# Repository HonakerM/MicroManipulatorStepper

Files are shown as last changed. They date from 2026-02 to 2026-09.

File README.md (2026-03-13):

# Open Micro-Manipulator

This project contains an open source low-cost, easy-to-build motorized **XYZ Micro-Manipulator** motion control platform achieving submicron precision.
It's designed for applications such as optical alignment, probing electronic components, and microscopy.

Check out the YouTube video for more information about the device and how it is built:<br>
[An Open Source Motorized XYZ Micro-Manipulator - Affordable sub µm Motion Control](https://youtu.be/MgQbPdiuUTw)

<div style="display: flex; gap: 2%;">
  
  
</div>

Thanks to its parallel kinematic structure and miniature ball joints, it achieves good mechanical stiffness and a large range of motion.
The motors are off the shelf stepper motors driven by a 30 kHz closed loop controller and a very precise PWM signal.
A 'magnetic gearing' approach increases the resolution of the low-cost magnetic rotary encoders by a factor of 30 allowing for steps down to 50nm
(**Please mind the difference between resolution and accuracy**. The absolute accuracy is significantly worse.

The device can be controlled via simple G-Code commands over a USB serial interface and is thus easily integrated into other projects.
The firmware implements a complete motion planning stack with look-ahead for smooth and accurate path following capabilities.

## Getting Started

Below is a list of high level steps you can follow if you want to replicate the project. 
If you have questions or problems with the build or just want to discuss subjects related to the project, 
joint the projects community [Discord Server](https://discord.gg/maRvMVpa2Q).

1. Read this Document and watch the linked videos
2. Get the parts listed in [Bill of Materials](documentation/bom/bom.md)
3. Build the device and electronics
4. Change the hardware configuration according to your build [hw_config.h](firmware/MotionControllerRP/src/hw_config.h)
5. Upload firmware using VSCode with PlattformIO plugin
6. Calibrate axis

## ✨NEW: Hardware Version 4.0
A new version of the hardware has been released, fixing several issues with the previous design:

- Self collision during homing fixed.
- Connection of ball joint block with screws only was not well constrained and could rotated a bit.
- No reliable way to ensure consistent linkage rod length
- Unnecessary ball joint friction
- Accurate ball position heavily dependet on print quality and corner rounding
- Rubber bands could not be changed or removed once glued in.

A video about the improved ball joint and linkage manufactoring process can be found on YT: [Better Ball Joints for the Open Micro-Manipulator](https://www.youtube.com/watch?v=NM2KXvRGmpg)
Also the FreeCAD model was restructured and improved and now includes all pins and fasteners. It now provides a reference for all required mechanical parts. 

<div style="display: flex;">
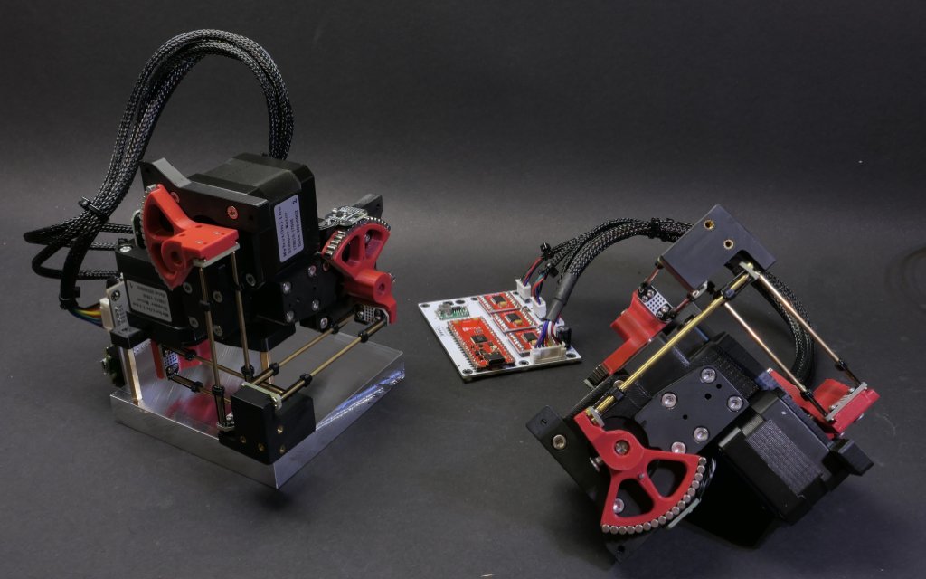
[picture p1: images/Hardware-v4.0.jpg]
Open Micro-Manipulator GUI
    
</div>

WARNING: BOM is not updated yet...

## Open Micro-Manipulator GUI
To make testing and using the Open-Micro Manipulator easy and convenient a python control program with a graphical user interface is provided here: [Open Micro-Manipulator GUI](https://github.com/0x23/OpenMicroManipulatorGUI).
It has simple controlls to move the device around, while also displaying a live camera feed (e.g. from a microscope camera). Additional features, include a simple g-code runner and realtime mouse control (e.g. for Biology applications).

<div style="display: flex;">
    Open Micro-Manipulator GUI
</div>

## 🐍 Python-API

The lightweight Python API handles all serial communication and provides convenient command execution and debug message printing.
The interface includes functions to home, move, and calibrate the device, as well as to query device information.
Simply copy the [open_micro_stage_api.py](software/PythonAPI/open_micro_stage_api.py) file into your project (also install the dependencies in requirements.txt), and you’re ready to get started.

## Usage Example
```python
from open_micro_stage_api import OpenMicroStageInterface

# create interface and connect
oms = OpenMicroStageInterface(show_communication=True, show_log_messages=True)
oms.connect('/dev/ttyACM0')

# run this once to calibrate joints
# for i in range(3): oms.calibrate_joint(i, save_result=True)

# home device
oms.home()

# move to several x,y,z positions [mm]
oms.move_to(0.0, 0.0, 0.0, f=10)
oms.move_to(3.1, 4.1, 5.9, f=26)
oms.move_to(0.0001, 0.0, 0.0, f=10)

# wait for moves to finish
oms.wait_for_stop()
```

## API Functions (most relevant functions only)
```python
connect(port, baud_rate=921600)
disconnect()
set_workspace_transform(transform)
get_workspace_transform()
home(axis_list=None)
calibrate_joint(joint_index, save_result)
move_to(x, y, z, f, move_immediately, blocking, timeout)
set_tool_output(tool_idx, output_value, immediate)
set_pose(x, y, z)
dwell(time_s, blocking, timeout)
enable_motors(enable)
wait_for_stop(polling_interval_ms, disable_callbacks)
set_max_acceleration(linear_accel, angular_accel)
set_servo_parameter(pos_kp, pos_ki, vel_kp, vel_ki, vel_filter_tc)
```
## ✨ Firmware v1.0.4

Firmware 1.0.4 comes with many smaller improvements and bugfixes and a great new feature as well:

 - **Tools**: Tool usage (for example for laser engraving) is now supported on the two GPIO pins of J5 on the pcb.
              Tools are integrated into the planner and run fast and with correct timing when executing g-code.
              The tools support PWM (using the PIO feature to squeeze out extra channels without relying on software PWM).

   Example usage:
   ```
     M3 T0 S0.7  // set pwm output of tool 0 to 70%
     G4 S0.001   // dwell command (or any other motion command) - necessary to apply the tools output
   ```
   
- **Calibration**: Calibration has now some addition error checks to improve error reporting of potential problems like encoder alignment.
- **Kinematic Model Parameter**: Initialization code has been cleaned up and better comments where added to the parameters. Parameters are preset for HW v4.0 but you can toggle back to the old HW-v3.0 parameters if necessary.
- **Bugfixes**: smaller bugfixes

IMPORTANT: If you have **Hardware Version v3.0** you need to switch back to the old kinematic parameters in the [kinematic_model_delta3d.cpp](firmware/MotionControllerRP/src/kinematic_models/kinematic_model_delta3d.cpp) file (there is an #define for that at the top).

## Firmware v1.0.1

This update improves calibration, homing, logging, and adds several new G-Code commands.

### Improvements
- **Homing**: parallel homing support, higher repeatability, more accurate geometric reference  
- **Joint calibration**: refined procedure, persistent flash storage (no recalibration after reboot)  
- **Logging**: clearer and more detailed output  

### New G-Code Commands
- `G28` — Home joints (supports homing multiple axis simultanously for faster startup)
- `G24` — Set pose command (directly sets servo targets, bypassing motion controller)  
- `M17/M18` — Enable/Disable motors (with pose recovery from encoders on enable)  
- `M51` — Read encoder values  
- `M55` — Set servo loop parameters 
- `M56` — Joint calibration (with save-to-flash option)  
- `M57` — Read various information about the device state  
- `M58` — Read firmware version

## ⚙ CAD-Files

All CAD models are made in **FreeCAD** to allow everyone to view and modify the design without subscribing or paying for a proprietary CAD solution.
Note that most components are already designed with the goal to make them easily machinable on a 3-Axis CNC-Mill.
You can also 3D-Print the parts but have to live with thermal drift (carbon filled filaments can reduce this problem).

<div style="display: flex;">
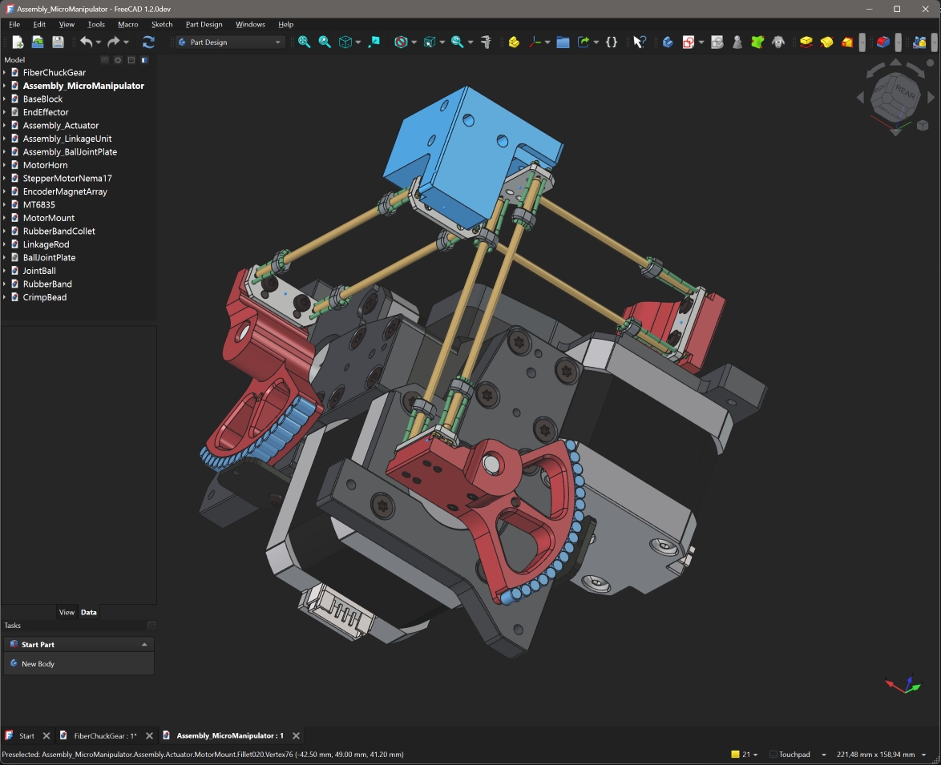
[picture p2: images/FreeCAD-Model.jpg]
FreeCAD Model
    
</div>

<br>

The CAD files can be found here: [CAD Models](construction).
Please note that FreeCAD version **1.2.0dev** was used, and the files might not work with older versions.

STL files for printing can be found here: [STL Files](construction/STL_3D_Printing/)

## ⚙ Kinematic Model

The kinematic model is defined here: [kinematic_model_delta3d.cpp](firmware/MotionControllerRP/src/kinemtaic_models/kinematic_model_delta3d.cpp).
Please check the dimensions of your build against the values set in the constructor. In particular, make sure the arm length matches.

## ⚙ Electronics

IMPORTANT: If you fabricated PCB version v1.2 (see version label on the board) you need to drill out a misplaced via on diode D1 that shorts 5V rail to ground (See [repair image](electronics/pcb_v1.2_fix.jpg) ). The problem was fixed in v1.3.

The electronics are designed in **KiCAD** and only commonly available modules (motor drivers and MCU boards) are used and connected by a simple PCB. No SMD soldering is required to populate the board to make the build extra accessible.
For usual winding resistance of your motors, the device should be powered by $${\color{lightgreen} 5V-6V }$$ (2A) to keep current and heating to a reasonable level.

<div style="display: flex; gap: 5%;">
  
  
</div>

The repository now also contains the fabrication files that can be directly uploaded to the PCB manufacturer.

## ⚙ Firmware

The firmware is written in C++ and takes some inspiration from the 'SimpleFOC' project. It aims to be streamlined and readable without any extra fuss, focusing on the hardware used in this project.
It implements path planning with look-ahead and, unlike many other motion controller projects, supports true 6DOF-Pose interpolation and planning, making it ready for driving hexapod motion platforms; that may or may not be the next step for this project.

You may find configuration for pin numbers, motor type, and other parameters in [hw_config.h](firmware/MotionControllerRP/src/hw_config.h). Please check them before uploading the firmware.

<div style="display: flex; gap: 2%;">
  
  
</div>

### Building and Flashing the Firmware

For building and flashing the firmware, Visual Studio Code (available for free on Windows and Linux) is recommended.
Install the PlatformIO add-on and open the firmware folder. You can now build and flash the firmware like any other PlatformIO project.

## ⚙ G-Code Interface

The firmware supports only a small subset of G-Code commands listed below.  
Each command is acknowledged with either an **`ok`** or **`error`** response.  

If a command provides additional information (e.g., the *get position* command), that information is returned **before** the `ok` message.  
The client must wait for an acknowledgment from the previous command before sending the next one—otherwise, behavior is undefined.
| Command | Description |
|---|---|
| `G0 X Y Z F` | Move the end-effector in a straight line to the specified position. <br>• `X`, `Y`, `Z`: target positions <br>• `F`: feed rate |
| `G1 X Y Z F` | Same as `G0`. |
| `G4 S/P` | Dwell/pause for a specified time. <br>• `S`: seconds <br>• `P`: milliseconds |
| `G24 X Y Z A B C` | Directly set current pose for servo loops with optional rotation vector* `A`, `B`, `C`. |
| `G28 A-F` | Home one or more joints. <br>• Optional joint selection `A`–`F`. |
| `M3` | Set Tool output. <br>• `T`: tool index <br>• `S`: output value (0.0..1.0) <br> Note: new values is only applied on the next motion or dwell command |
| `M17` | Enable motors and read current pose as the start pose. |
| `M18` | Disable motors. |
| `M50` | Get current internal pose. (Encoders are not read here) |
| `M51` | Get current encoder angles (in degrees) and raw encoder values. |
| `M52` | Get the number of items in the planner queue. |
| `M53` | Check if all planned moves are finished (`1` = finished, `0` = not finished). |
| `M55 A B C D F` | Set servo loop parameters. <br>• `A`, `B`: position PI controller gains (P and I) <br>• `C`, `D`: velocity PI controller gains (P and I) <br>• `F`: velocity filter time constant |
| `M56 J S` | Calibrate a joint. <br>• `J`: joint index <br>• `S`: save calibration result |
| `M57` | Get device and servo loop info: homing/calibration state, angles, loop frequencies, and file list. |
| `M58` | Get firmware version. |
| `M204 L A` | Set linear and angular acceleration. <br>• `L`: linear acceleration <br>• `A`: angular acceleration |

*Note: The communication protocol uses 3D vectors for rotations. The direction represents the rotation axis and the length of the vector represents the angle of rotation around the axis.

## ❤️ Support

If you'd like to support this project, consider the following:

- **Contribute to the build guide** – Help improve or expand the build instructions by submitting pull requests or opening issues with suggestions.
- **Characterize typical radial stepper motor shaft error motion** – Measure radial error motion of the shaft of multiple Nema-17 stepper motors (see Cylos Garage for more information about the subject: https://www.youtube.com/watch?v=gt2gK-oxy5s).
- **Give feedback on the build experience** – Let us know what worked, what didn’t, and how the process could be smoother for others.
- **Support the project on Ko-fi** – If you find this project valuable, you can support it financially via [Ko-fi](https://ko-fi.com/diffractionlimited) ☕.

## Youtube Video
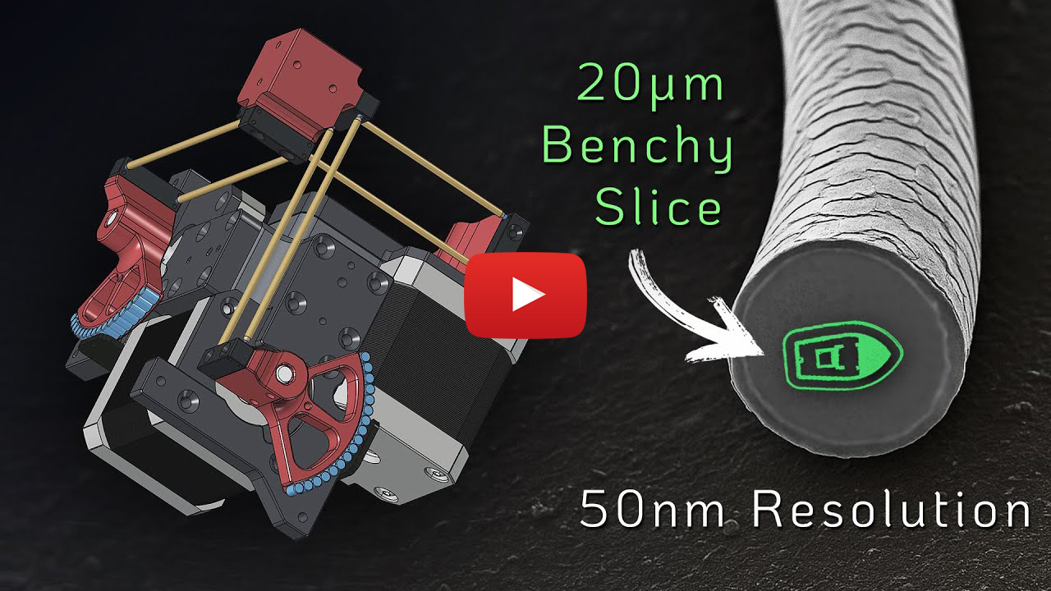
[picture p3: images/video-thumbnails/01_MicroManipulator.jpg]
Watch the video (https://youtu.be/MgQbPdiuUTw)

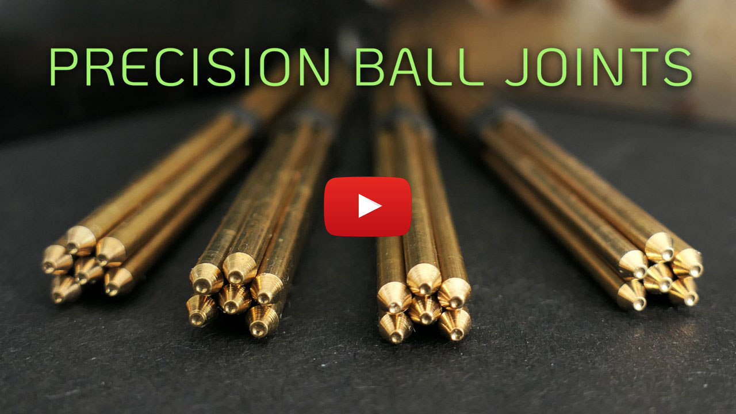
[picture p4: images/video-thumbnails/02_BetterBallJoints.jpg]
Better Ball Joints for the Open Micro-Manipulator (https://youtu.be/MgQbPdiuUTw)


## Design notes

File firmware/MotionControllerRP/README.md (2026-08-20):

# MotionControllerRP -- pico-sdk + FreeRTOS port

This is a port of the original PlatformIO / arduino-pico project to plain CMake +
pico-sdk + FreeRTOS, targeting the Raspberry Pi Pico 2 (RP2350). See
[`lib/README.md`](lib/README.md) for the three git submodules you need before building,
and build instructions.

## What changed, and why

**The two bare-metal busy loops are now FreeRTOS tasks.** `main_core0()`
(command-parser + path-planner) and `main_core1()` (servo control) used to be
un-yielding `while(true)` loops, one launched via arduino-pico's `setup()`/`loop()` on
core 0, the other via `multicore_launch_core1()` on core 1. They're now two FreeRTOS
tasks (`command_task` / `servo_task` in `src/main.cpp`), each pinned to its own core
with `vTaskCoreAffinitySet()`, running under the dual-core SMP FreeRTOS port
(`RP2350_ARM_NTZ`, from the `raspberrypi/FreeRTOS-Kernel` fork). This gives you actual
task/scheduler visibility (stack high-water marks, the ability to add more tasks
later, mutexes/queues that interoperate with `pico_sync`, etc.) instead of the cores
being permanently and opaquely owned by one loop each.

**Both tasks still run essentially flat-out**, matching the original behaviour: each
loop iteration ends with `taskYIELD()` rather than a real `vTaskDelay()`, so no
artificial rate limit is imposed on either the command-parsing/path-planning loop or
the servo control loop's update rate (the servo loop still computes its own `dt` from
`time_us_64()` every iteration, exactly as before). `taskYIELD()` just gives the
scheduler on that core a chance to run the idle task / timer service / anything else
you add later, without slowing this one down.

If you'd rather have the servo loop run at a fixed, deterministic rate instead (e.g.
to guarantee CPU headroom on core 1 for future tasks, at the cost of some peak
throughput), there's a comment in `servo_task()` in `main.cpp` showing how to swap the
`taskYIELD()` for a `vTaskDelayUntil()` against a fixed period.

**Arduino-framework dependencies were replaced with a small compatibility layer**
(`src/compat/`), rather than rewriting the control/kinematics/servo code itself:

| Arduino API | Replaced by | Backed by |
|---|---|---|
| `Serial` | `compat/Serial_compat.*` | pico-sdk stdio over USB CDC |
| `Wire` / `TwoWire` | `compat/Wire_compat.*` | pico-sdk `hardware_i2c` |
| `LittleFS` / `File` | `compat/LittleFS_compat.*` | [pico-vfs](https://github.com/oyama/pico-vfs) (POSIX `fopen`/`opendir`/`stat` on littlefs-over-flash) |
| `delay()` / `delayMicroseconds()` | `compat/Arduino_compat.h` | `sleep_ms()` / `sleep_us()` |

This was a deliberate choice: everything else in this codebase (SPI encoders, the
PWM/PIO motor driver, hardware timers, the multicore spinlocks) was already written
directly against pico-sdk, not Arduino, so the actual Arduino surface area in use was
small and self-contained. Shimming it kept the diff to the control/robotics logic
essentially zero, versus a much riskier full rewrite of files that are hard to
re-verify by eye (PID loops, kinematics, calibration).

One piece of dead code was dropped rather than ported: a `NeoPixelConnect` status-LED
object was instantiated in `robot.cpp` but never actually used anywhere. If you want
status-LED support back, drive the WS2812 directly with the PIO program from
`pico-examples/pio/ws2812` and wire it into `set_led_color()` in `main.cpp`.

**Calibration data (`LittleFS`) and single-core flash writes.** pico-vfs's flash
block device already wraps its erase/program operations in pico-sdk's
`flash_safe_execute()`, which is the mechanism that keeps flash writes safe with
respect to code executing (from flash) on the other core. Per your note, all flash
writes in this project happen from a single core, which is the simpler and
lower-risk case; you shouldn't need `PICO_COPY_TO_RAM` for that. If you ever do move
calibration saves to run from both cores, re-check pico-vfs's
[`LIMITATION.md`](https://github.com/oyama/pico-vfs/blob/main/LIMITATION.md#file-system-limitations)
first.

**Overclocking, hardware timers, multicore spinlocks, SPI encoders, and the PIO-based
motor driver are all unchanged** -- they were already plain pico-sdk and didn't need
touching.

## Verified

This exact tree (with the three submodules from `lib/README.md` checked out) was
built end-to-end against a real `arm-none-eabi-gcc` + `cmake`/`ninja` toolchain while
this port was put together, and compiled and linked cleanly into a `.uf2`. A handful
of real issues surfaced only by actually compiling it were fixed along the way:
missing `hardware_pio`/`hardware_dma` link libraries, a couple of Arduino-only macros
(`PI`, `DEG_TO_RAD`) with no pico-sdk equivalent, and a couple of missing standard
includes (`hardware/sync.h`, `<cstdio>`) that arduino-pico used to pull in for free
via `Arduino.h`.

## Suggested next steps

- Build it yourself against your actual hardware and confirm the servo loop's
  achieved update rate matches what you had before (it should, given the
  `taskYIELD()`-not-`vTaskDelay()` choice above, but worth confirming on-device).
- If you add more tasks later (telemetry, a watchdog, etc.), give them explicit
  priorities/affinities in `main.cpp` alongside `command_task`/`servo_task`.
- `configTOTAL_HEAP_SIZE` in `FreeRTOSConfig.h` is set to 128KB and
  `PICO_FS_DEFAULT_SIZE`/the `pico_enable_filesystem(... SIZE ...)` call in
  `src/CMakeLists.txt` reserves 512KB of flash for the littlefs volume -- both are
  reasonable starting points, tune to taste.

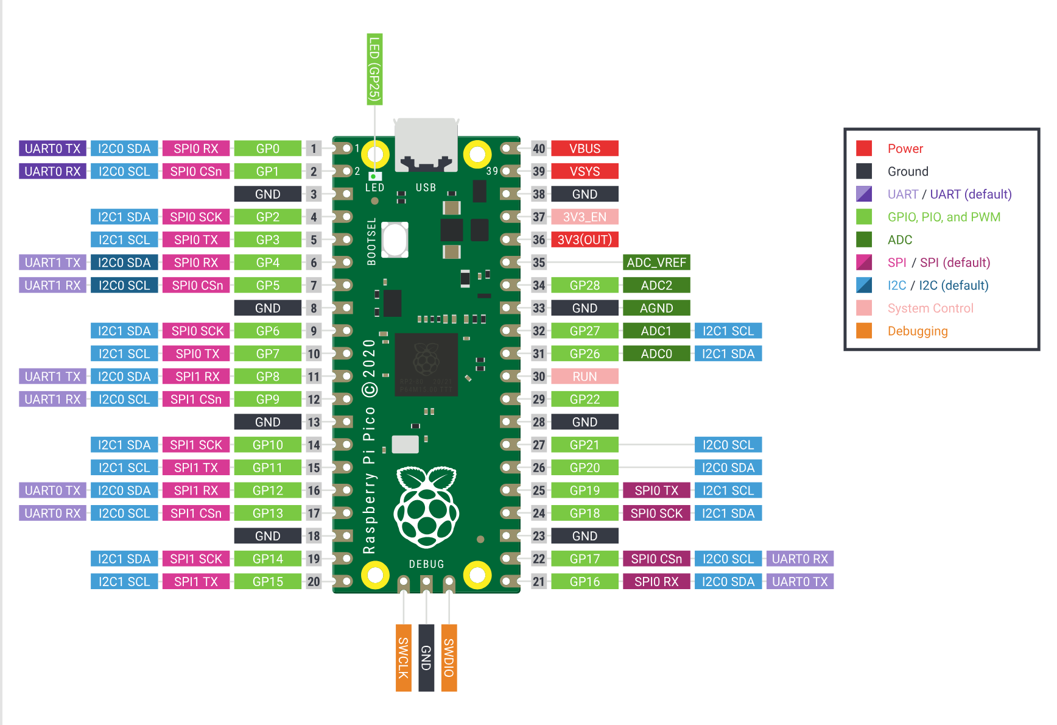
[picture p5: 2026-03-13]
firmware/MotionControllerRP/Rp2350-Pico_Pinout.png

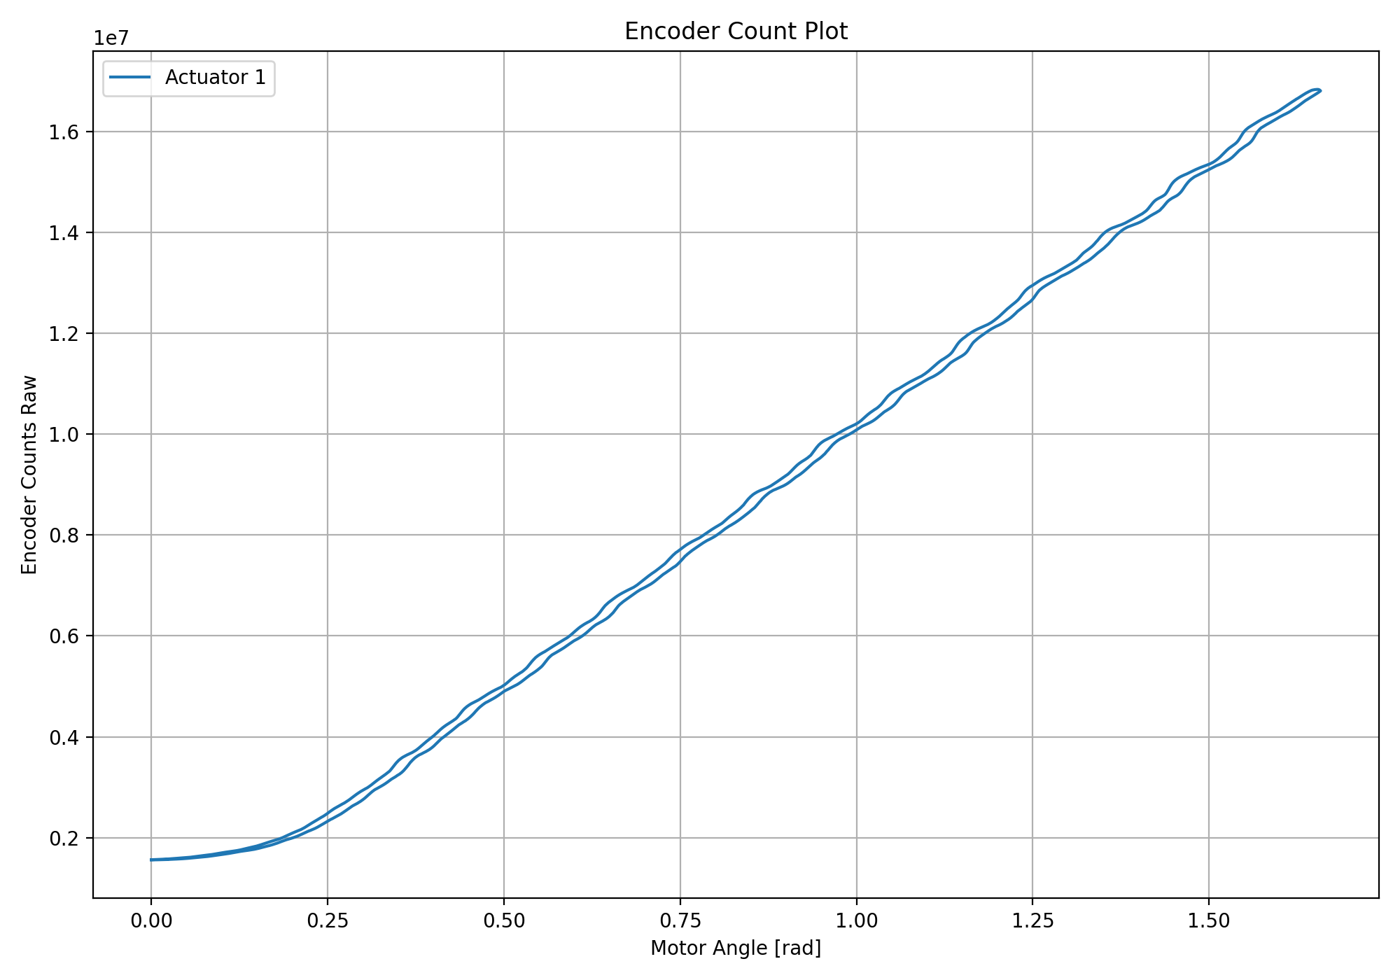
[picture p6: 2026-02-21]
software/PythonAPI/my_figure.png

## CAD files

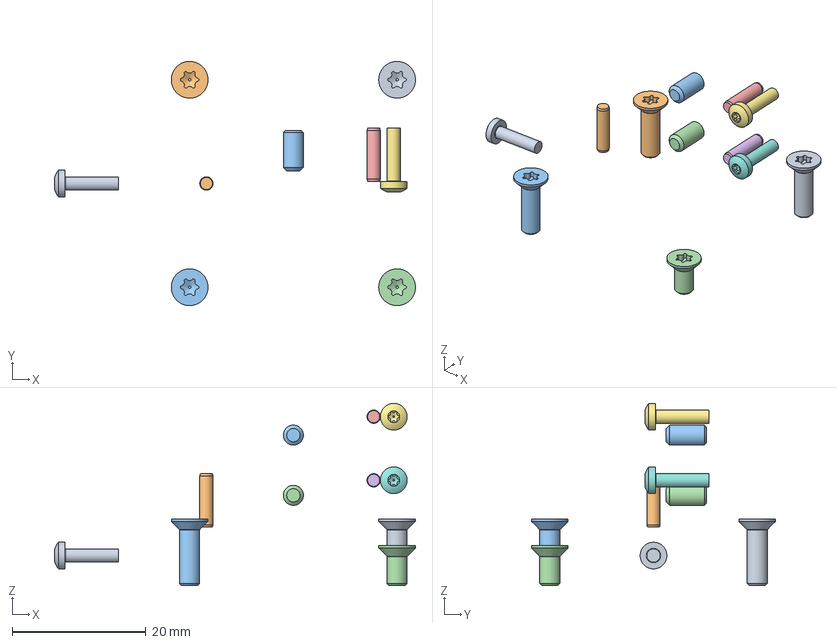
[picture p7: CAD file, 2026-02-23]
construction/micro_manipulator/Assembly_Actuator.FCStd
53.9 x 36.5 x 27.2 mm
M3x10-Screw x 2
M3x10-Screw008 x 2
M3x10-Screw009 x 2
M3x6-Screw x 2
2 mmx8-Pin x 2
2 mmx8-Pin012 x 2
M2x8-Screw x 2
M2x8-Screw009 x 2
M2x8-Screw004 x 2
2 mmx8-Pin011 x 2
M3x6-Screw003 x 2
M3x6-Screw004 x 2

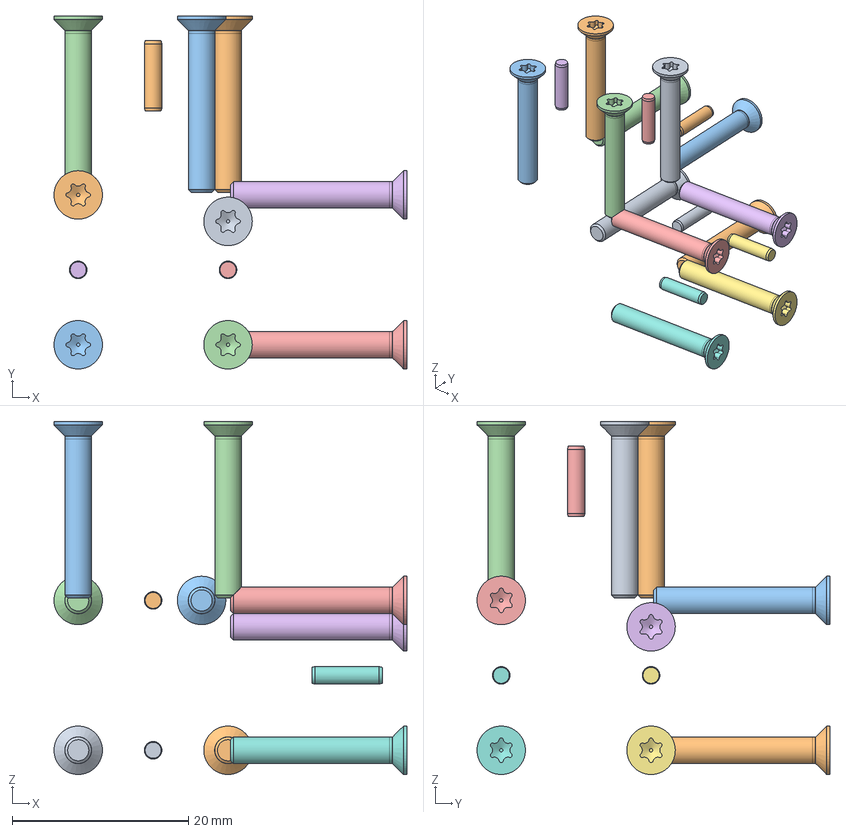
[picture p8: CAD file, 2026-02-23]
construction/micro_manipulator/Assembly_MicroManipulator.FCStd
40.0 x 40.0 x 40.0 mm
M3x20-Screw x 2
M3x20-Screw281 x 2
M3x20-Screw282 x 2
M3x20-Screw283 x 2
M3x20-Screw277 x 2
M3x20-Screw278 x 2
M3x20-Screw279 x 2
M3x20-Screw280 x 2
M3x20-Screw262 x 2
M3x20-Screw263 x 2
M3x20-Screw264 x 2
M3x20-Screw265 x 2
2 mmx8-Pin027 x 2
2 mmx8-Pin028 x 2
2 mmx8-Pin029 x 2
2 mmx8-Pin030 x 2
2 mmx8-Pin031 x 2
2 mmx8-Pin032 x 2

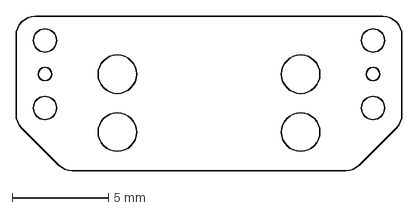
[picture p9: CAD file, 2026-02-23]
construction/micro_manipulator/balljoint_plate_pcb/BallJointPlate-Contour.dxf
20.0 x 8.00 mm

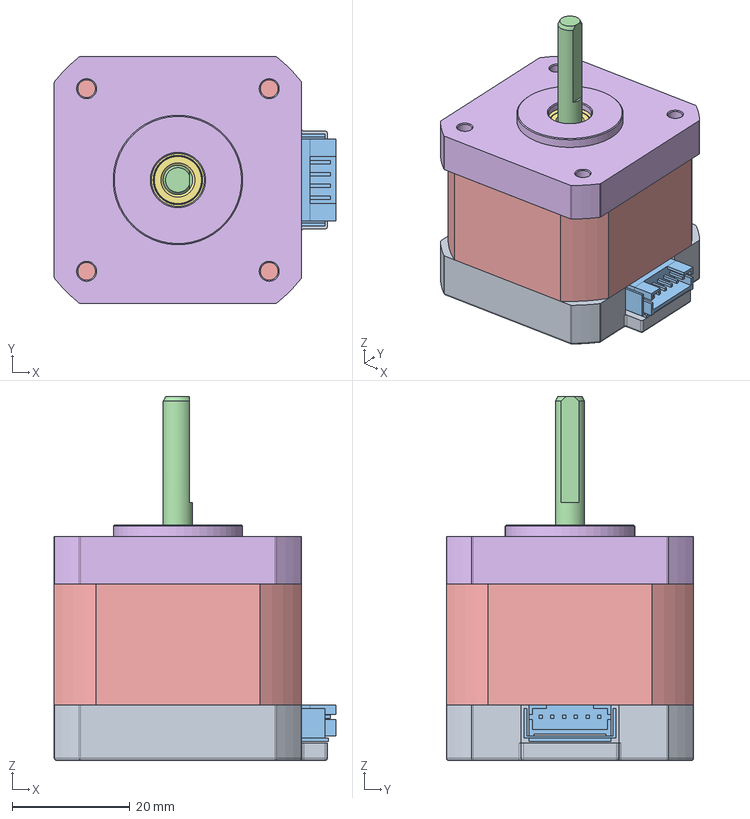
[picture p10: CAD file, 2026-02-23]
construction/micro_manipulator/StepperMotorNema17.FCStd
47.8 x 42.0 x 61.8 mm
rear end cap
rear bearing
connector
shaft
stator
front end cap
front bearing
M3x10-Screw
M3x10-Screw004
M3x10-Screw005
M3x10-Screw006

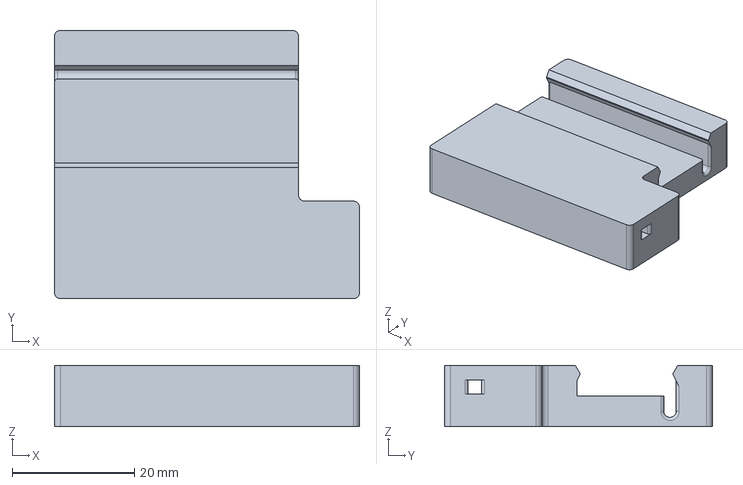
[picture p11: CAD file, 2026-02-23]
construction/tools/rod_embossing_tools/rod_lenth_setting_press/rod_guide.FCStd
50.0 x 44.0 x 10.0 mm

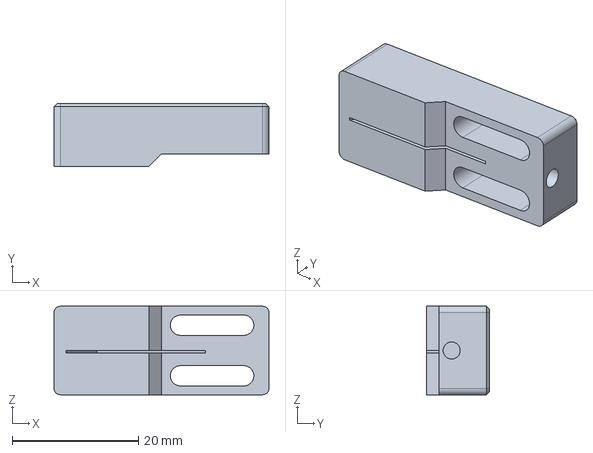
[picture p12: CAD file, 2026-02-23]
construction/tools/rod_embossing_tools/rod_sharper/BladeCarrier.FCStd
34.0 x 10.0 x 14.0 mm

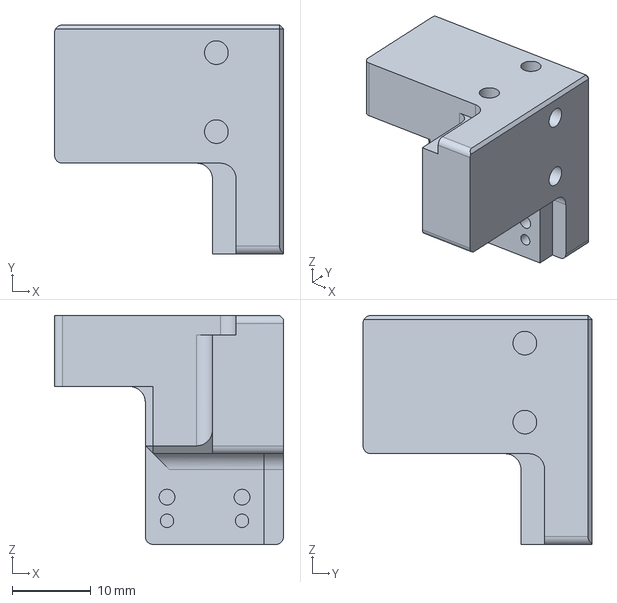
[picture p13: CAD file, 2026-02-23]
construction/micro_manipulator/EndEffector.FCStd
29.0 x 29.0 x 29.0 mm

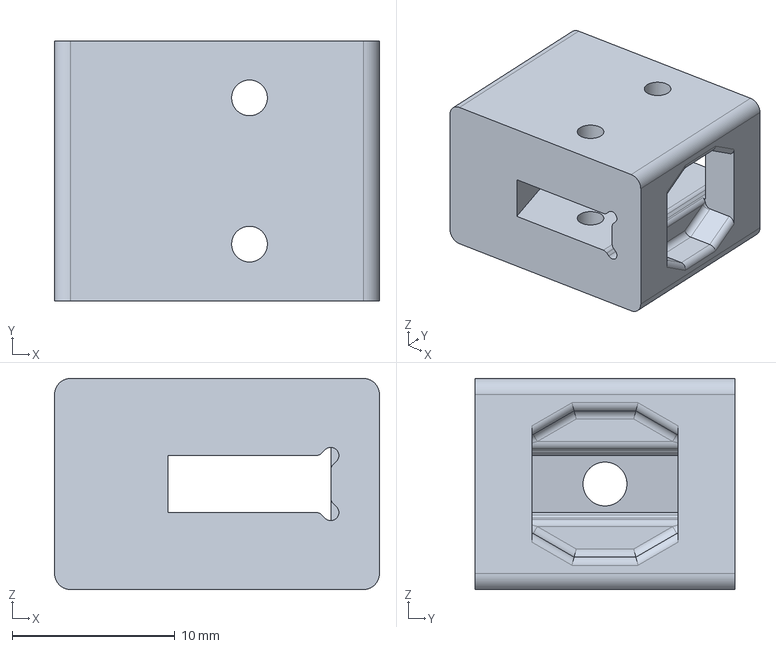
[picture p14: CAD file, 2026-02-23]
construction/tools/rod_embossing_tools/rod_lenth_setting_press/caliper_clamp.FCStd
20.0 x 16.0 x 13.0 mm

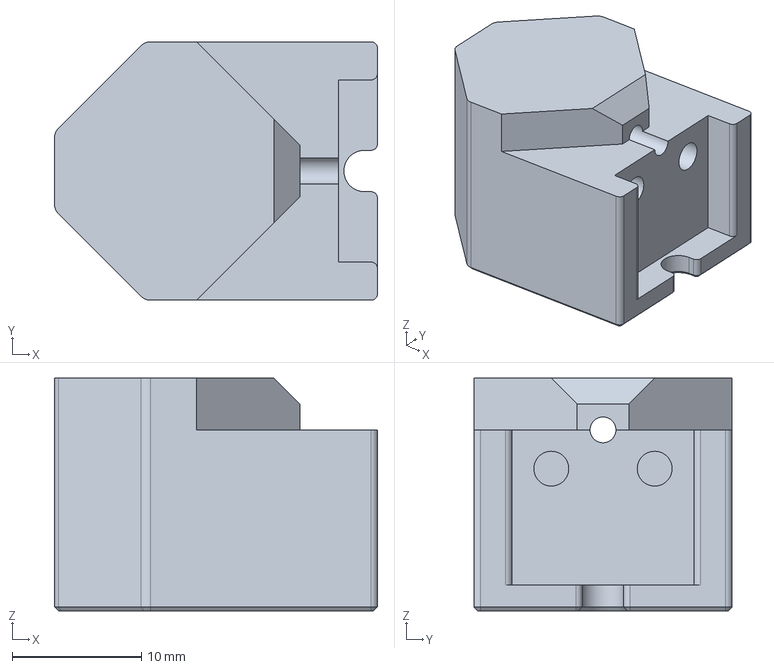
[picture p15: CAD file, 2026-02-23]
construction/tools/rod_embossing_tools/rod_sharper/RodGuide.FCStd
25.0 x 20.0 x 18.0 mm

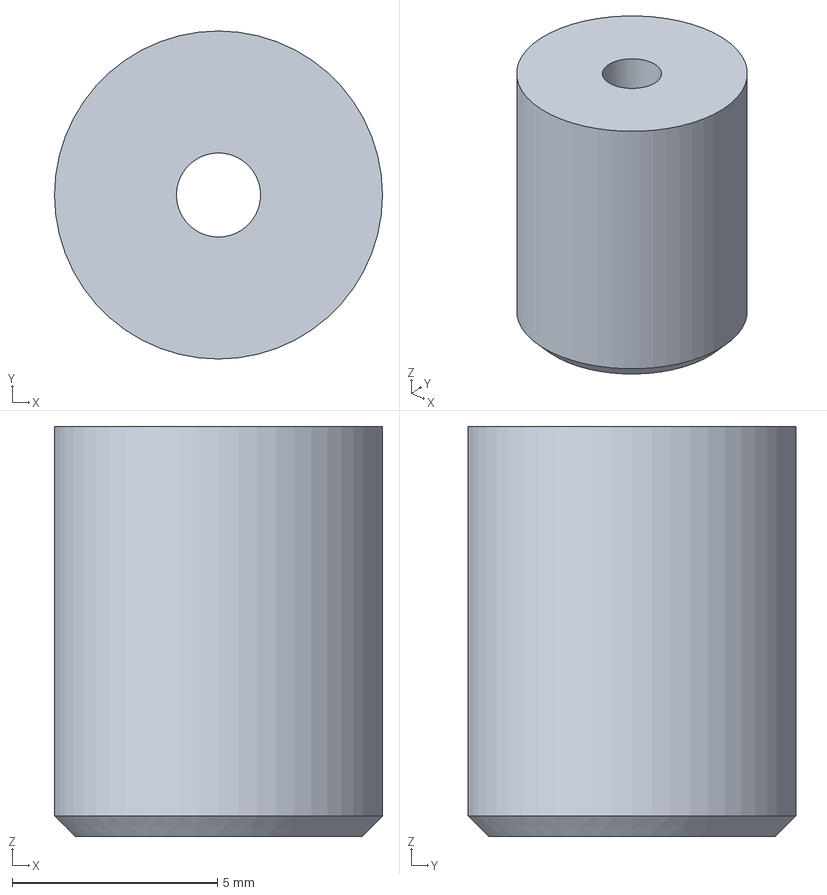
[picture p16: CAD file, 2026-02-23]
construction/tools/rod_embossing_tools/rod_lenth_setting_press/rod_collet.FCStd
8.00 x 8.00 x 10.0 mm

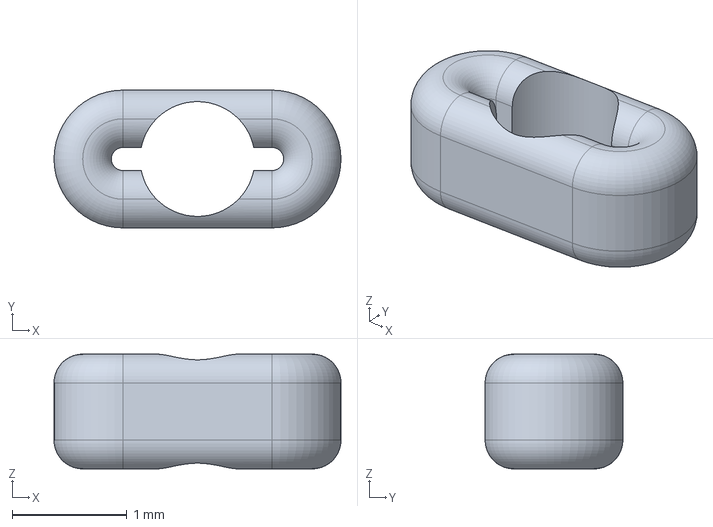
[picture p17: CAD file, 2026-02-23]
construction/micro_manipulator/CrimpBead.FCStd
2.50 x 1.20 x 1.00 mm

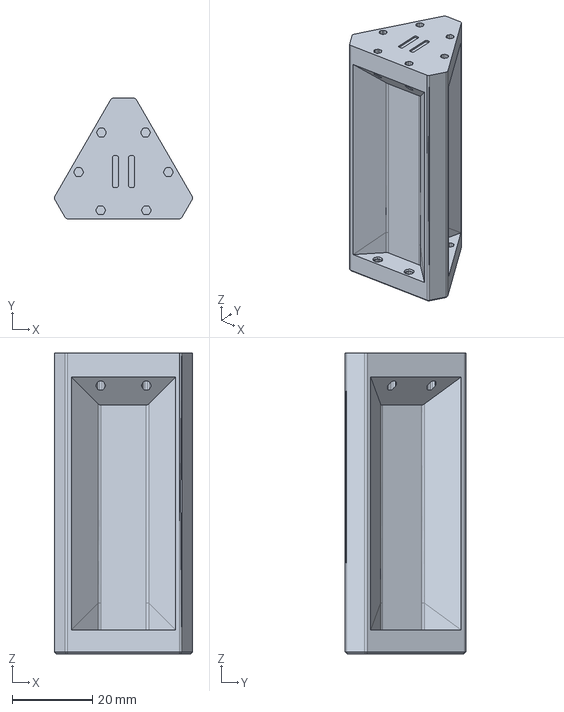
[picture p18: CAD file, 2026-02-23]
construction/tools/rod_embossing_tools/rod_lenth_setting_press/RodGrindingJig_B.FCStd
34.5 x 30.1 x 75.0 mm

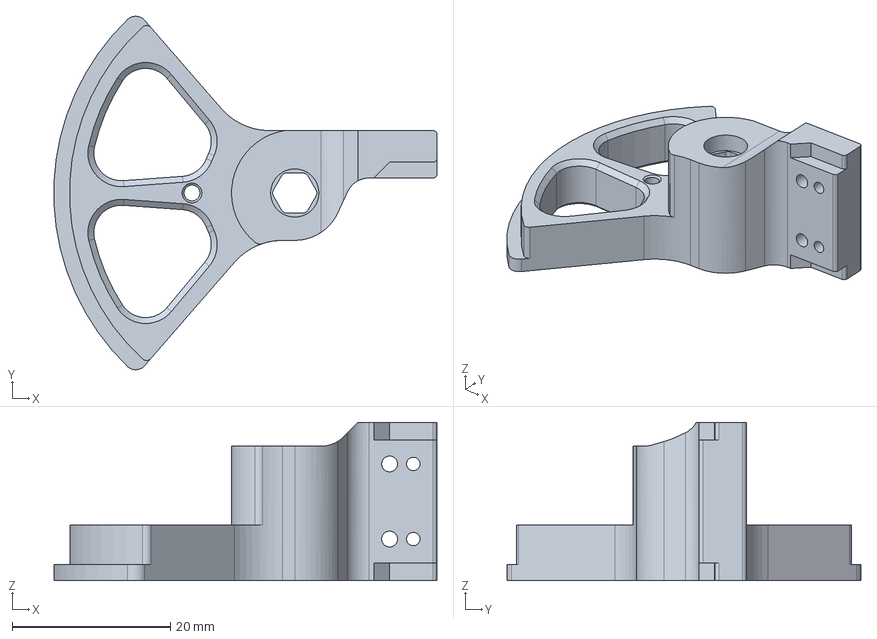
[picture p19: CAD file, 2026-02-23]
construction/micro_manipulator/MotorHorn.FCStd
48.5 x 44.7 x 20.0 mm

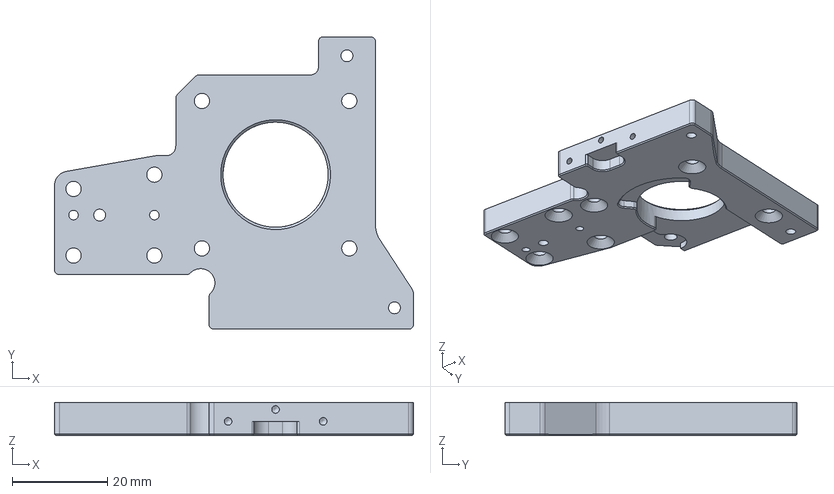
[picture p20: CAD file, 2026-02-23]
construction/micro_manipulator/MotorMount.FCStd
75.5 x 61.5 x 7.00 mm

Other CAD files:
construction/micro_manipulator/Assembly_EndEffector.FCStd
construction/micro_manipulator/Assembly_BallJointPlate.FCStd
construction/micro_manipulator/Assembly_LinkageUnit.FCStd
construction/tools/rod_embossing_tools/rod_lenth_setting_press/RodGrindingJig_A.FCStd
construction/micro_manipulator/BallJointPlate.FCStd
construction/micro_manipulator/BaseBlock.FCStd
construction/micro_manipulator/EncoderMagnet.FCStd
construction/micro_manipulator/EncoderMagnetArray.FCStd
construction/micro_manipulator/JointBall.FCStd
construction/micro_manipulator/LinkageRod.FCStd
construction/micro_manipulator/MT6835.FCStd
construction/micro_manipulator/RubberBand.FCStd
construction/micro_manipulator/RubberBandCollet.FCStd

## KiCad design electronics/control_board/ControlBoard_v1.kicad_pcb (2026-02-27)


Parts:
A1: RaspberryPi_Pico; RaspberryPi_Pico_Common_Unspecified
C1, C2, C3: C_Polarized; CP_Radial_D8.0mm_P3.50mm
C4, C5, C6: C; C_0603_1608Metric_Pad1.08x0.95mm_HandSolder
D1: 1N5819; D_DO-41_SOD81_P10.16mm_Horizontal
D2: PMEG4010; D_SOD-123F
H1, H2, H3, H4, H5, H6: MountingHole_Pad; MountingHole_2.7mm_M2.5_Pad_Via
J1: Motor1; PinHeader_1x04_P2.54mm_Vertical
J2: Motor2; PinHeader_1x04_P2.54mm_Vertical
J3: Motor3; PinHeader_1x04_P2.54mm_Vertical
J4: Encoder; JST_PH_B8B-PH-K_1x08_P2.00mm_Vertical
J5: I2C; JST_PH_B4B-PH-K_1x04_P2.00mm_Vertical
J7: Power; AMASS_XT60-M_1x02_P7.20mm_Vertical
R1, R2: 4K7; R_0603_1608Metric_Pad0.98x0.95mm_HandSolder
U1, U2, U3: ROB-14450; MODULE_ROB-14450; PARTREV 11-13-17
U4: DCDC_Converter; DCDC_17mmx12mm

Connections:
+3.3V: A1.36 (3V3), C4.1, C5.1, C6.1, J4.2, J5.4, R1.1, R2.1, U1.2 (VCC), U2.2 (VCC), U3.2 (VCC)
+5V: A1.39 (VSYS), D1.1 (K), D2.1 (K)
+12V: C1.1, C2.1, C3.1, J7.2, U1.1 (VM), U2.1 (VM), U3.1 (VM), U4.2 (IN+)
/Encoder1_CS: A1.26 (GPIO20), J4.6
/Encoder2_CS: A1.27 (GPIO21), J4.7
/Encoder3_CS: A1.29 (GPIO22), J4.8
/Encoder_MISO: A1.1 (GPIO0), J4.4
/Encoder_MOSI: A1.5 (GPIO3), J4.3
/Encoder_SCK: A1.4 (GPIO2), J4.5
/I2C_SCL: A1.21 (GPIO16), J5.3, R1.2
/I2C_SDA: A1.22 (GPIO17), J5.2, R2.2
/Motor1_A1: A1.17 (GPIO13), U1.14 (AI1)
/Motor1_A2: A1.16 (GPIO12), U1.15 (AI2)
/Motor1_B1: A1.19 (GPIO14), U1.12 (BI1)
/Motor1_B2: A1.20 (GPIO15), U1.11 (BI2)
/Motor2_A1: A1.12 (GPIO9), U2.14 (AI1)
/Motor2_A2: A1.11 (GPIO8), U2.15 (AI2)
/Motor2_B1: A1.14 (GPIO10), U2.12 (BI1)
/Motor2_B2: A1.15 (GPIO11), U2.11 (BI2)
/Motor3_A1: A1.7 (GPIO5), U3.14 (AI1)
/Motor3_A2: A1.6 (GPIO4), U3.15 (AI2)
/Motor3_B1: A1.9 (GPIO6), U3.12 (BI1)
/Motor3_B2: A1.10 (GPIO7), U3.11 (BI2)
/MotorEN: A1.24 (GPIO18), U1.13 (STBY), U2.13 (STBY), U3.13 (STBY)
/MotorPWM: A1.25 (GPIO19), U1.10 (PWMB), U1.16 (PWMA), U2.10 (PWMB), U2.16 (PWMA), U3.10 (PWMB), U3.16 (PWMA)
GND: A1.3 (GND), A1.8 (GND), A1.13 (GND), A1.18 (GND), A1.23 (GND), A1.28 (GND), A1.33 (AGND), A1.38 (GND), C1.2, C2.2, C3.2, C4.2, C5.2, C6.2, J4.1, J5.1, J7.1, U1.3 (GND), U1.8 (GND), U1.9 (GND), U2.3 (GND), U2.8 (GND), U2.9 (GND), U3.3 (GND), U3.8 (GND), U3.9 (GND), U4.1 (IN-), U4.3 (OUT-)
unnamed: D1.2 (A), D2.2 (A), U4.4 (OUT+)
unnamed: J1.1, U1.7 (B01)
unnamed: J1.2, U1.6 (B02)
unnamed: J1.3, U1.5 (A02)
unnamed: J1.4, U1.4 (A01)
unnamed: J2.1, U2.7 (B01)
unnamed: J2.2, U2.6 (B02)
unnamed: J2.3, U2.5 (A02)
unnamed: J2.4, U2.4 (A01)
unnamed: J3.1, U3.7 (B01)
unnamed: J3.2, U3.6 (B02)
unnamed: J3.3, U3.5 (A02)
unnamed: J3.4, U3.4 (A01)

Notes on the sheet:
PWM pin is usually not used in this application and is always 1
Motor Driver 2
Power
Interfaces
Motor Driver 1
Motor Driver 3
Mechanical
Populate one of these diodes.
Micro Controller



Board: 2 copper layers, 64.0 x 85.0 mm, 27 parts (6 on the bottom side), 39 nets.

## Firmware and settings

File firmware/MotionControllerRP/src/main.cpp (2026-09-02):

// --------------------------------------------------------------------------------------
// Project: MicroManipulatorStepper
// License: MIT (see LICENSE file for full description)
//          All text in here must be included in any redistribution.
// Author:  M. S. (diffraction limited)
// --------------------------------------------------------------------------------------

#include "main.h"

#include "hardware/clocks.h"
#include "hardware/pll.h"
#include "hardware/vreg.h"

#include <Wire.h>
#include <algorithm>

#include "robot.h"
#include "utilities/logging.h"
#include "utilities/frequency_counter.h"
#include "kinematic_models/kinematic_model_delta3d.h"
#include "version.h"
#include "hw_config.h"
#include "LittleFS.h"

#include "demo_gcode_generator.h"

//*** GLOBALS ***************************************************************************

// NeoPixelConnect strip(PIN_BUILTIN_LED, 1);
Robot robot(0.01f);

/*
MT6835Encoder encoder1(spi0, PIN_ENCODER1_CS);
MT6835Encoder encoder2(spi0, PIN_ENCODER2_CS);
MT6835Encoder encoder3(spi0, PIN_ENCODER3_CS);

TB6612MotorDriver motor_driver1(
  PIN_MOTOR_EN, PIN_M1_PWM_A_POS, PIN_M1_PWM_A_NEG, PIN_MOTOR_PWMAB,
  PIN_MOTOR_EN, PIN_M1_PWM_B_POS, PIN_M1_PWM_B_NEG, PIN_MOTOR_PWMAB
);
TB6612MotorDriver motor_driver2(
  PIN_MOTOR_EN, PIN_M2_PWM_A_POS, PIN_M2_PWM_A_NEG, PIN_MOTOR_PWMAB,
  PIN_MOTOR_EN, PIN_M2_PWM_B_POS, PIN_M2_PWM_B_NEG, PIN_MOTOR_PWMAB
);
TB6612MotorDriver motor_driver3(
  PIN_MOTOR_EN, PIN_M3_PWM_A_POS, PIN_M3_PWM_A_NEG, PIN_MOTOR_PWMAB,
  PIN_MOTOR_EN, PIN_M3_PWM_B_POS, PIN_M3_PWM_B_NEG, PIN_MOTOR_PWMAB
);

ServoController servo_controller1(motor_driver1, encoder1, 400/4);
ServoController servo_controller2(motor_driver2, encoder2, 400/4);
ServoController servo_controller3(motor_driver3, encoder3, 400/4);
FrequencyCounter loop_freq_counter(1000);

PathPlanner planner(0.01f);
MotionController motion_controller(&planner);
Pose6DF current_pose;

CommandParser command_parser; */

//*** FUNCTIONS *************************************************************************

// Run before setup()
//__attribute__((constructor))
void overclock() {
  vreg_set_voltage(VREG_VOLTAGE_1_20);         // For >133 MHz
  busy_wait_us(10 * 1000);  // 10 ms delay
  set_sys_clock_khz(250000, true);             // Set to 250 MHz
}

void set_led_color(uint8_t r, uint8_t g, uint8_t b) {
 /* strip.neoPixelSetValue(0, r, g, b, false);
  delayMicroseconds(2000);
  strip.neoPixelShow(); */
}

void led_blink(uint8_t r, uint8_t g, uint8_t b, int count, int period_time_ms) {
  for(int i=0; i<count; i++) {
    gpio_put(PIN_BUILTIN_LED, 1);
    // set_led_color(r, g, b);
    sleep_ms(period_time_ms/2);
    // set_led_color(0, 0, 0);
    gpio_put(PIN_BUILTIN_LED, 0);
    sleep_ms(period_time_ms/2);
  }
}

void main_core0() {
  uint64_t last_time = time_us_64();

  #ifdef DEMO_MODE
    auto* demo_gcode_generator = new DemoGcodeGenerator(&robot);
    demo_gcode_generator->run();  // blocks forever
  #endif

  while(true) {
    // update motion controller
    robot.update_command_parser();
    robot.update_path_planner();
    robot.check_servo_loop();
  }
}

void main_core1() {
  LOG_INFO("Starting servo controll loops on core 1...");

  uint64_t last_time = time_us_64();
  while(true) {
    // get time and detla time
    uint64_t time_us = time_us_64();
    float dt = float(time_us - last_time)*1e-6f;
    if(dt < 20e-6f) continue;
    last_time = time_us;


    // limit time delta
    // dt = std::min(dt, 0.0001f);

    // update servo loops
    robot.update_servo_controllers(dt);
  }
}

void setup() {
  gpio_init(PIN_BUILTIN_LED);
  gpio_set_dir(PIN_BUILTIN_LED, GPIO_OUT);
  
  led_blink(0, 0, 30, 3, 100);
  // stdio_init_all();  // Initializes USB or UART stdio
  overclock();
  // Serial.begin(921600);
  Logger::instance().begin(921600, REQUIRE_SERIAL_ON_STARTUP);

  set_led_color(50, 10, 0);
  // auto* test = new KinematicModel_Delta3D(); test->test(); delete test;

  delay(100);  // Allow time for serial monitor to connect
  
  LOG_INFO("Open Micro Stage Firmware: %s", FIRMWARE_VERSION);
  LOG_INFO("System clock: %i Mhz", int32_t(clock_get_hz(clk_sys))/1000/1000);

  // LittleFS.format();
  if (!LittleFS.begin()) {
    LOG_ERROR("Mounting filesystem failed");
  } else {
    FSInfo fs_info;
    LittleFS.info(fs_info);
    LOG_INFO("Mounting filesystem successfully [%i/%i bytes used]", 
             (int)fs_info.usedBytes, (int)fs_info.totalBytes);
  } 

  /*
  LookupTable enc_to_pos_lut;
  bool res = true; 
  res &= load_lut_from_file(enc_to_pos_lut, "joint_0_pos_to_field_lut.dat");
  for(uint32_t i=0; i<enc_to_pos_lut.size(); i++) {
    float v = enc_to_pos_lut.get_entry(i);
    Serial.printf("%i, %d\n", i, int(v*1000));
  }

    // Close files
  Serial.println("File print complete");*/
  LOG_INFO("Initializing device...");
  robot.init();

  multicore_launch_core1(&main_core1);
  sleep_ms(100);
  
  set_led_color(0, 20, 0);
  LOG_INFO("Initialization finished");
  LOG_INFO(" ");

  gpio_put(PIN_BUILTIN_LED, 1);

  return;

  /*
  rotencoder_wire.setSDA(PIN_ENCODER_SDA);
  rotencoder_wire.setSCL(PIN_ENCODER_SCL);
  rotencoder_wire.begin();
  rotencoder_wire.setClock(1000000);
  encoder.init();
  encoder.set_hysteresis(0x4); //0x6);
  */
}

void loop() {
  main_core0();
}

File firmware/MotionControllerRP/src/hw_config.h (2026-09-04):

#pragma once
#include <cstdint>
#include "utilities/math_constants.h"

// #define DEMO_MODE

//--- MOTORS ------------------------------------------------------------------

// motor pole pair count
//  * 100 for 0.9deg stepper motors
//  * 50  for 1.8deg stepper motors
constexpr float MOTOR1_POLE_PAIRS = 50;
constexpr float MOTOR2_POLE_PAIRS = 50;
constexpr float MOTOR3_POLE_PAIRS = 50;

// max current factor in range [0..1]. Lower values reduce pwm resolution so a
// value above 0.4 is recommended.
constexpr float MOTOR_MAX_CURRENT_FACTOR = 0.60f;

constexpr float MAX_MOTOR_STALL_COUNT = 500;

constexpr float MAX_MOTOR_DT_TIME = 0.001f;

//--- ENCODERS ----------------------------------------------------------------

// Conversion factor from encoder angle (one 2pi period every two magnets) to rotor angle.
// Used when the system can not rely on calibration data being present (e.g. during homing)
constexpr float ENCODER_MAGNET_PITCH = 3.0f;    // [mm]
constexpr float ENCODER_MAGNET_RADIUS = 30.0f;  // [mm]
constexpr float ENCODER_ANGLE_TO_ROTOR_ANGLE = (ENCODER_MAGNET_PITCH*2.0f) / 
                                               (ENCODER_MAGNET_RADIUS * Constants::TWO_PI_F);
#define ENCODER_SPI_FREQUENCY 1000000 // [Hz] - max 1MHz for MT6835 encoder

                                               
// enables error checking for encoders (slow) - useful for debugging
// Note: some chips seem to return always a crc of 0 producing massiv false errors       
constexpr bool ENABLE_ENCODER_CRC = false;

// Probes the chip crc at startup and enables crc checking only if the chip actually
// produces a valid crc. This makes ENABLE_ENCODER_CRC safe to leave off: chips with a
// working crc get the extra protection, broken ones simply keep it disabled.
constexpr bool ENCODER_CRC_AUTODETECT = true;

// --- encoder read validation -------------------------------------------------
// A corrupted spi frame is indistinguishable from real motion for the phase unwrapping
// in MT6835Encoder, and a single bad frame permanently offsets the absolute position.
// Suspicious samples are therefore re-read and, if still bad, skipped.

// number of extra spi reads attempted when a sample fails validation
constexpr int ENCODER_READ_RETRIES = 2;

// Fastest rotor motion considered physically possible [rad/s]. A sample implying a step
// faster than this is treated as corrupted data, not motion. Keep this well above any
// velocity the machine can reach (including being pushed by hand) - the whole calibrated
// range is only about 1.3 rad, so 50 rad/s traverses it in ~26 ms.
constexpr float MAX_PLAUSIBLE_MOTOR_VELOCITY = 50.0f;

// After this many rejected reads in a row the sample is accepted anyway to keep the servo
// loop from going blind, and an encoder fault is reported (position may have jumped).
// At 6 kHz this is about 10 ms of consecutive bad data.
constexpr uint32_t MAX_CONSECUTIVE_ENCODER_REJECTS = 64;

//--- HOMING ------------------------------------------------------------------

constexpr float HOMING_VELOCITY   = 1.0f;        // rad per s
constexpr float HOMING_CURRENT    = 0.5f;       // range 0..1
// NOT IMPLEMENTED YET: constexpr float HOMING_FINISH_POS = 0.5f;        // in rad
constexpr float HOMING_RETRACTION_FIELD_ANGLE = 8.0f;
constexpr float HOMING_RETRACTION_Z_FIELD_ANGLE = 8.0f;
constexpr float CALIBRATION_RETRACTION_FIELD_ANGLE = 0.25f;

//--- CALIBRATION -------------------------------------------------------------

// degrees from home position
constexpr float CALIBRATION_RANGE = 75; 

// velocity of the magnetic field during calibration (lower is more accurate)
constexpr float CALIBRATION_FIELD_VELOCITY = 20.0f; 

// size of the calibration lookup table
constexpr int ENCODER_LUT_SIZE = 256;

//--- CLOSED LOOP CONTROL -----------------------------------------------------

// position controller 
constexpr float POS_KP = 60.0f;
constexpr float POS_KI = 30000.0f;

// velocity controller
constexpr float VEL_LOWPASS_TC = 0.004f;
constexpr float VEL_KP = 0.2f;
constexpr float VEL_KI = 90.0f;

//--- KINEMATIC ---------------------------------------------------------------

// Kinematic Parameters are defined kinematic_modes/kinematic_model_delta3d.cpp

// NUM_JOINTS and NUM_TOOLS are defined in 'path_segment.h'. Note that changing
// the number of joints requires changing the kinematic model accordingly and
// also requires the initialization of the correct number of 'RobotJoint' objects
// in the Robtos init method.


//--- CONNECTION ------------------------------------------------------------------

#define REQUIRE_SERIAL_ON_STARTUP false


//--- PERIPHERAL ------------------------------------------------------------------
#define PERIPHERAL_ENABLED true
#define PERIPHERAL_REQUIRED false
#define PERIPHERAL_I2C_ADDRESS 0x10
#define PERIPHERAL_I2C_INSTANCE i2c0
#define PERIPHERAL_I2C_SDA_PIN 16
#define PERIPHERAL_I2C_SCL_PIN 17
#define PERIPHERAL_I2C_CLOCK 30000
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

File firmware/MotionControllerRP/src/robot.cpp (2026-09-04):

// --------------------------------------------------------------------------------------
// Project: MicroManipulatorStepper
// License: MIT (see LICENSE file for full description)
//          All text in here must be included in any redistribution.
// Author:  M. S. (diffraction limited)
// --------------------------------------------------------------------------------------

#include <LittleFS.h> 
#include "robot.h"
#include "hw_config.h"
#include "utilities/logging.h"
#include "utilities/utilities.h"
#include "kinematic_models/kinematic_model_delta3d.h"
#include "servo_control/homing_controller.h"
#include "servo_control/actuator_calibration.h"
#include "robot_joint/robot_joint.h"
#include "pico/multicore.h"
#include "version.h"
#include "robot_tool/pwm_tool.h"

constexpr int SPINLOCK_ID_SHARED_DATA = 0;
constexpr int SPINLOCK_ID_JOINTS = 1;

#include <NeoPixelConnect.h>
NeoPixelConnect led(PIN_BUILTIN_LED, 1);

//*** FUNCTION **************************************************************************

bool startswith(const std::string& str, const std::string& prefix) {
    return str.size() >= prefix.size() &&
           std::equal(prefix.begin(), prefix.end(), str.begin());
}

//*** CLASS *****************************************************************************

//--- Robot -----------------------------------------------------------------------------

Robot::Robot(float path_segment_time_step) : 
  path_planner(nullptr, path_segment_time_step), 
  motion_controller(&path_planner),
  servo_loop_frequency_counter(10000),
  motion_controller_frequency_counter(1000),
  shared_data(SPINLOCK_ID_SHARED_DATA),
  joints_spin_lock(spin_lock_instance(SPINLOCK_ID_JOINTS))
{
  kinematic_model = new KinematicModel_Delta3D();
  path_planner.set_kinematic_model(kinematic_model);  

  for(int i=0; i<NUM_JOINTS; i++)
    joints[i] = nullptr;

  command_parser.set_command_processor(this);

  current_feedrate = LinearAngular(10.0f, 1.0f);
  max_acceleration = LinearAngular(500.0f, 50.0f);
  path_buffering_time_us = 50*1e3;

  for(int i=0; i<NUM_TOOLS; i++)
    robot_tools[i] = nullptr;

  state = ERobotState::IDLE;
  peripheral = nullptr;
}

Robot::~Robot() {
  if(kinematic_model != nullptr)
    delete kinematic_model;

  for(int i=0; i<NUM_JOINTS; i++) {
    if(joints[i] != nullptr)
      delete joints[i];
    joints[i] = nullptr;
  }
}

void Robot::init() {
  MT6835Encoder::setup_spi(spi0, PIN_ENCODER_SCK, PIN_ENCODER_MOSI, PIN_ENCODER_MISO, ENCODER_SPI_FREQUENCY);

  // axis 1
  {
    auto* encoder = new MT6835Encoder(spi0, PIN_ENCODER1_CS);
    auto* motor_driver = new TB6612MotorDriver(
      PIN_MOTOR_EN, PIN_M1_PWM_A_POS, PIN_M1_PWM_A_NEG, PIN_MOTOR_PWMAB,
      PIN_MOTOR_EN, PIN_M1_PWM_B_POS, PIN_M1_PWM_B_NEG, PIN_MOTOR_PWMAB
    );
	encoder->set_crc_enabled(ENABLE_ENCODER_CRC);
    joints[0] = new RobotJoint(encoder, motor_driver, MOTOR1_POLE_PAIRS);
  }

  // axis 2
  {
    auto* encoder = new MT6835Encoder(spi0, PIN_ENCODER2_CS);
    auto* motor_driver = new TB6612MotorDriver(
      PIN_MOTOR_EN, PIN_M2_PWM_A_POS, PIN_M2_PWM_A_NEG, PIN_MOTOR_PWMAB,
      PIN_MOTOR_EN, PIN_M2_PWM_B_POS, PIN_M2_PWM_B_NEG, PIN_MOTOR_PWMAB
    );
	encoder->set_crc_enabled(ENABLE_ENCODER_CRC);
    joints[1] = new RobotJoint(encoder, motor_driver, MOTOR2_POLE_PAIRS);
  }

  // axis 3
  {
    auto* encoder = new MT6835Encoder(spi0, PIN_ENCODER3_CS);
    auto* motor_driver = new TB6612MotorDriver(
      PIN_MOTOR_EN, PIN_M3_PWM_A_POS, PIN_M3_PWM_A_NEG, PIN_MOTOR_PWMAB,
      PIN_MOTOR_EN, PIN_M3_PWM_B_POS, PIN_M3_PWM_B_NEG, PIN_MOTOR_PWMAB
    );
	encoder->set_crc_enabled(ENABLE_ENCODER_CRC);
    joints[2] = new RobotJoint(encoder, motor_driver, MOTOR3_POLE_PAIRS);
  }

  // initialize axes
  for(int i=0; i<NUM_JOINTS; i++) {
    joints[i]->init(i);
    joints[i]->load_calibration();
  }

  // Arm the encoder read validation. A corrupted spi frame otherwise feeds straight into
  // the phase unwrapping and permanently offsets the joint position.
  {
    // fastest plausible step expressed in raw encoder counts per microsecond
    const float counts_per_rotor_rad = float(MT6835_CPR) / 
                                       (Constants::TWO_PI_F*ENCODER_ANGLE_TO_ROTOR_ANGLE);
    const float max_counts_per_us = counts_per_rotor_rad*MAX_PLAUSIBLE_MOTOR_VELOCITY*1e-6f;

    for(int i=0; i<NUM_JOINTS; i++) {
      auto* encoder = joints[i]->encoder;
      encoder->set_read_filter(ENCODER_READ_RETRIES, max_counts_per_us, 
                               MAX_CONSECUTIVE_ENCODER_REJECTS);
      if(ENCODER_CRC_AUTODETECT && encoder->is_initialized())
        encoder->autodetect_crc();
    }
  }

  // add tools
  robot_tools[0] = new PwmTool();
  ((PwmTool*)robot_tools[0])->init(PIN_TOOL1, 8000, 8);

  robot_tools[1] = new PwmTool();
  ((PwmTool*)robot_tools[1])->init(PIN_TOOL2, 8000, 8);

  // add peripherals if enabled
  if(PERIPHERAL_ENABLED) {
    i2c_handle = new TwoWire(PERIPHERAL_I2C_INSTANCE, PERIPHERAL_I2C_SDA_PIN, PERIPHERAL_I2C_SCL_PIN);
    peripheral = new Peripheral(i2c_handle);
    peripheral->begin(PERIPHERAL_REQUIRED);
  }

  // setup timer for updating the motion controller (which evaluates joint space path
  // segments and produces the current target position for the servo loops)
  float motion_controller_update_time_us = 500;
  add_repeating_timer_us(-motion_controller_update_time_us, 
                         Robot::update_motion_controller_isr, 
                         (void*)this, 
                         &motion_controller_update_timer);
}


void Robot::update_command_parser() {
  // process serial input
  if (Serial.available()) {
    char c = Serial.read();
    command_parser.add_input_character(c);
    // Serial.write(c);
  }

  // update command parse which will queue command to the path planner
  command_parser.update();

  // TESTING:
  //sleep_ms(10);
  //float pos_error = joints[1]->servo_controller->get_position_error();
  //LOG_INFO(">pos_error [µrad]: %f\n", pos_error*1e6);
  //Serial.printf(">pos_error [µrad]: %f\n", pos_error*1e6);#
  //LOG_INFO(">pos_x [mm]: %f", joints[1]->position);
  //update_servo_controllers(0.01f);
}
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

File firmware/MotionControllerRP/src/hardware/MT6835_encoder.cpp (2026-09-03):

// --------------------------------------------------------------------------------------
// This code is a modified version of the MT6835 Driver from the SimpleFOC project
// being distributed under the MIT liscence as well. Thank you SimpleFOC !
// --------------------------------------------------------------------------------------

#include "MT6835_encoder.h"
#include "hardware/spi.h"
#include "hardware/gpio.h"
#include "pico/stdlib.h"
#include "utilities/logging.h"
#include <hw_config.h>

void MT6835Encoder::setup_spi(spi_inst_t* spi, uint pin_sck, uint pin_mosi, uint pin_miso, int32_t baudrate_hz) {
  // Set GPIO functions to SPI
  gpio_set_function(pin_sck, GPIO_FUNC_SPI);
  gpio_set_function(pin_mosi, GPIO_FUNC_SPI);
  gpio_set_function(pin_miso, GPIO_FUNC_SPI);
  
  // SPI format: 8 bits, mode 3 (CPOL=1, CPHA=1)
  spi_init(spi, baudrate_hz);
  spi_set_format(spi, 8, SPI_CPOL_1, SPI_CPHA_1, SPI_MSB_FIRST);

  sleep_ms(10);
}

MT6835Encoder::MT6835Encoder(spi_inst_t* spi, int32_t cs_pin) : spi(spi), cs_pin(cs_pin) {
  if (cs_pin >= 0) {
      gpio_init(cs_pin);
      gpio_set_dir(cs_pin, GPIO_OUT);
      gpio_put(cs_pin, 1);  // CS high
  }
}

MT6835Encoder::~MT6835Encoder() {
  // nop
}

bool MT6835Encoder::init(uint8_t bandwidth, uint8_t hysteresis) {
  sleep_ms(100);

  if(is_connected() == false)
    return false;

  set_rotation_direction(0);    // needs to be set, otherwise might be random
  set_bandwidth(bandwidth);
  set_hysteresis(hysteresis);

  last_raw_angle = 0;
  abs_raw_angle = 0;
  crc_error_count = 0;
  last_good_read_time_us = 0;
  consecutive_bad_reads = 0;
  last_read_ok = true;
  read_fault = false;
  initialized = true;

  return true;
}

bool MT6835Encoder::is_connected() {
  uint8_t check_bytes[] = {37, 109, 179, 251, 1};
  for(int i=0; i<sizeof(check_bytes); i++) {
    write_register(MT6835_REG_USERID, check_bytes[i]);
    uint8_t user_id = read_register(MT6835_REG_USERID);
    if(user_id != check_bytes[i])
      return false;
  }

  return true;
}

bool MT6835Encoder::is_initialized() {
  return initialized;
}

void MT6835Encoder::reset_abs_angle(int32_t abs_raw_angle) {
  MT6835Encoder::abs_raw_angle = abs_raw_angle;
}

void MT6835Encoder::reset_abs_angle_period() {
  abs_raw_angle %= MT6835_CPR;
  if (abs_raw_angle < 0)
    abs_raw_angle += MT6835_CPR;
}

float MT6835Encoder::read_abs_angle() {
  int32_t raw_angle = read_abs_angle_raw();
  return raw_angle * RAW_TO_ANGLE;
}

// Reads a single angle frame. Returns false if crc checking is armed and the frame
// failed it, in which case 'raw_angle' still holds the (untrusted) value.
bool MT6835Encoder::read_raw_frame(int32_t& raw_angle) {
  uint8_t data[6] = {0};
  data[0] = MT6835_OP_ANGLE << 4;
  data[1] = MT6835_REG_ANGLE1;
  // rest zero

  spi_begin_transaction();
  spi_transfer(data, 6);
  spi_end_transaction();

  last_status = data[4] & 0x07;
  last_crc = data[5];
  raw_angle = ((int32_t)data[2] << 13) | ((int32_t)data[3] << 5) | (data[4] >> 3);

  if (check_crc && last_crc != calc_crc(raw_angle, last_status)) {
    last_status |= MT6835_CRC_ERROR;
    crc_error_count++;
    return false;
  }

  return true;
}

// The unwrapping in update_abs_raw_angle() can only resolve steps below half a period,
// and a real joint is far slower than that. Anything faster than the motor can physically
// move in the elapsed time is a corrupted sample, not motion.
bool MT6835Encoder::is_delta_plausible(int32_t raw_angle, uint32_t gap_us) const {
  const int32_t half_max = MT6835_CPR>>1;

  int32_t d = raw_angle - last_raw_angle;
  if (d > half_max) d -= MT6835_CPR;
  else if (d < -half_max) d += MT6835_CPR;
  int32_t ad = (d < 0) ? -d : d;

  // no trusted reference sample yet (first read after init/reset) -> nothing to compare to
  if(last_good_read_time_us == 0)
    return true;

  // no gate configured -> only the hard half period limit applies
  if(max_counts_per_us <= 0.0f)
    return ad < half_max;

  // allow a small fixed budget on top so encoder hysteresis and jitter never trip the gate
  float budget = max_counts_per_us*float(gap_us) + 64.0f;
  if(budget > float(half_max)) budget = float(half_max);

  return float(ad) <= budget;
}

MT6835Encoder::AbsRawAngleType MT6835Encoder::read_abs_angle_raw() {
  const uint64_t now = time_us_64();
  const uint32_t good_gap_us = (last_good_read_time_us != 0) ? 
                               (uint32_t)(now - last_good_read_time_us) : 0;

  // read, and re-read a few times if the sample looks corrupted
  int32_t raw_angle = 0;
  bool sample_ok = false;
  for(int attempt = 0; attempt <= read_retries; attempt++) {
    if(attempt > 0) diag.retries++;

    if(read_raw_frame(raw_angle) == false) {
      diag.crc_rejects++;
      continue;
    }
    if(is_delta_plausible(raw_angle, good_gap_us) == false) {
      diag.range_rejects++;
      diag.last_reject_delta = raw_angle - last_raw_angle;
      continue;
    }

    sample_ok = true;
    if(attempt > 0) diag.recovered_reads++;
    break;
  }

  if(sample_ok == false) {
    consecutive_bad_reads++;
    if(consecutive_bad_reads > diag.max_consecutive_bad)
      diag.max_consecutive_bad = consecutive_bad_reads;

    // The rejects are not going away, so this is not a glitch anymore. Holding the position
    // forever would leave the servo loop blind, so accept the sample to stay roughly in sync
    // and raise the fault flag - the absolute position can no longer be trusted.
    if(max_consecutive_rejects > 0 && consecutive_bad_reads >= max_consecutive_rejects) {
      diag.resyncs++;
      read_fault = true;
      consecutive_bad_reads = 0;
      last_read_ok = true;
      last_good_read_time_us = now;
      return update_abs_raw_angle(raw_angle);
    }

    // Skip: hold the last good position and, importantly, leave 'last_raw_angle' untouched
    // so the next accepted sample is unwrapped against the last trusted anchor.
    diag.skipped_reads++;
    last_read_ok = false;
    return abs_raw_angle;
  }

  consecutive_bad_reads = 0;
  last_read_ok = true;
  last_good_read_time_us = now;

  return update_abs_raw_angle(raw_angle);
}

MT6835Encoder::AbsRawAngleType MT6835Encoder::get_last_abs_raw_angle() const {
  return abs_raw_angle;
}

float MT6835Encoder::get_last_abs_angle() const {
  return abs_raw_angle * RAW_TO_ANGLE;
}

int32_t MT6835Encoder::get_rawcounts_per_rev() {
  return MT6835_CPR;
}

uint8_t MT6835Encoder::get_status() {
    return last_status;
}

void MT6835Encoder::set_crc_enabled(bool enable) {
  check_crc = enable;
}

bool MT6835Encoder::is_crc_enabled() {
  return check_crc;
}

void MT6835Encoder::set_read_filter(int retries, float max_counts_per_us, 
                                    uint32_t max_consecutive_rejects) {
  MT6835Encoder::read_retries = retries < 0 ? 0 : retries;
  MT6835Encoder::max_counts_per_us = max_counts_per_us;
  MT6835Encoder::max_consecutive_rejects = max_consecutive_rejects;
  MT6835Encoder::consecutive_bad_reads = 0;
}
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

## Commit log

2026-02-21 basic confic updates
    [data.csv]
2026-03-13 Update for my local version
    [output_0.csv, output_1.csv]
2026-03-20 Now broken :(
    [output_2.csv]
2026-06-23 Updated homing retraction field angle
2026-08-26 Update with better debugging and better RMS calculation
    [output_0.csv, output_1.csv, output_2.csv]
2026-08-27 Update with better logging around kinematics
2026-08-27 Update with position verification
    [output_0.csv, output_1.csv, output_2.csv]
2026-09-01 Update with better python api
    [output_1.csv]
2026-09-01 Broken but progress
    [output_0.csv, output_1.csv, output_2.csv]
2026-09-02 Fix servo0 logging
2026-09-04 Claude fixes :(
    [output_0.csv, output_1.csv, output_2.csv]
